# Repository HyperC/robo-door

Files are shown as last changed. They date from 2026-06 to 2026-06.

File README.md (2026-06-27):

# Automated Hidden Garage for a Roborock using ESP32 + ESPHome

A hidden garage door for the Roborock Qrevo Slim, controlled via ESPHome and Home Assistant.

Door opening and closing

## Installation Guide

### 1. Hardware

You'll need:

- **ESP32** — I used a Seeed XIAO ESP32-C6, but any ESP32 should work (C3, C6, SuperMini, etc.).
- **Metal gear servo** — I used a TD-8125MG (25 kg). It's just strong enough, although I ended up adding a counterweight to the door (explained later).
- **5V power supply** — I used a 5V / 2A adapter to power both the ESP32 and the servo.
- **(P)IR motion sensor** — Any small 5V-compatible (P)IR sensor should work.
- **3D printed parts** — Hinges, servo mount, and linkage arm (STLs attached). You could also build these from hardware store parts if your setup allows it.

### 2. Software

- Home Assistant
- ESPHome
- Roborock integration

## Door Preparation

Cut an opening large enough for the robot to pass through.

I recommend leaving roughly:

- **2–3 cm** clearance on each side
- **6–8 cm** above the robot

The extra height is needed because of the hinge design.

If possible, don't place the opening directly against a wall like I did. It makes the hinge design much more complicated.

If you're making the opening, consider cutting the top edge at roughly **45°**. When the door closes, the seam becomes much less visible and you can reduce the gap significantly.

For the door itself, use something lightweight. I used a thin piece of MDF, although lightweight plywood would probably be a better choice.

## Hinges

A normal piano hinge doesn't work very well here because:

- The hinges shouldn't be visible from the outside.
- There's no room for the door to swing inward — the robot is in the way.

Instead of rotating around a fixed pivot, the hinge creates an offset pivot point. This causes the top edge of the door to move inward first, after which the door rotates outward and upward.

Because my opening sits directly against a wall, I designed custom hinges that mount on top of the frame instead of inside it. STL files are in the [assets](./assets/) folder.

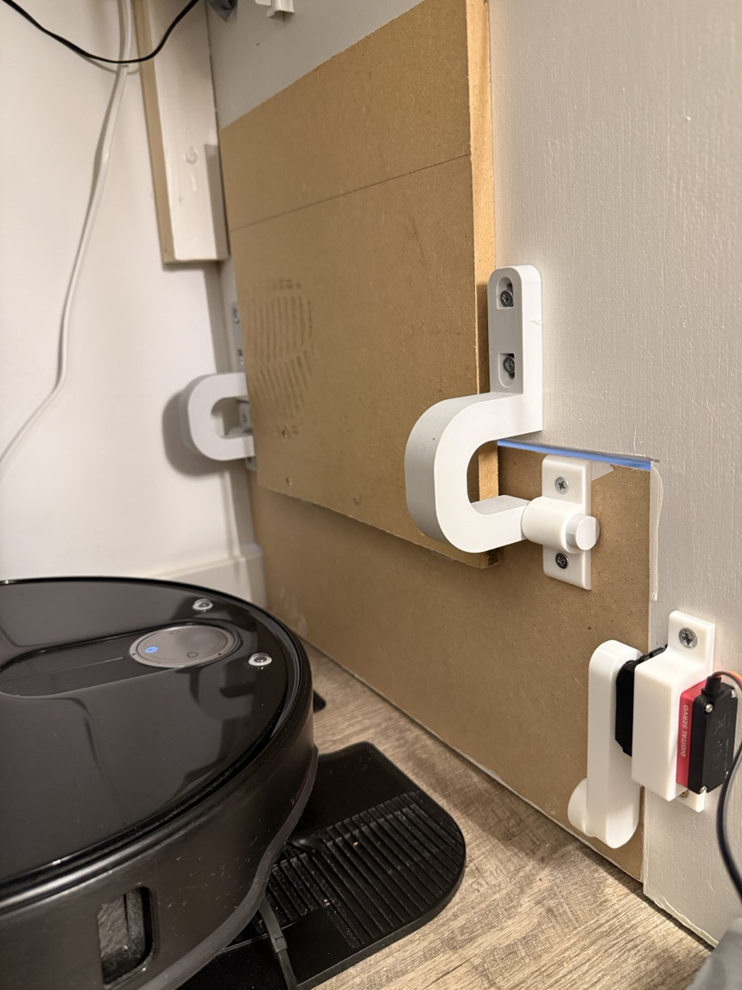
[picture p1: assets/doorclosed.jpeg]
Door closed from inside


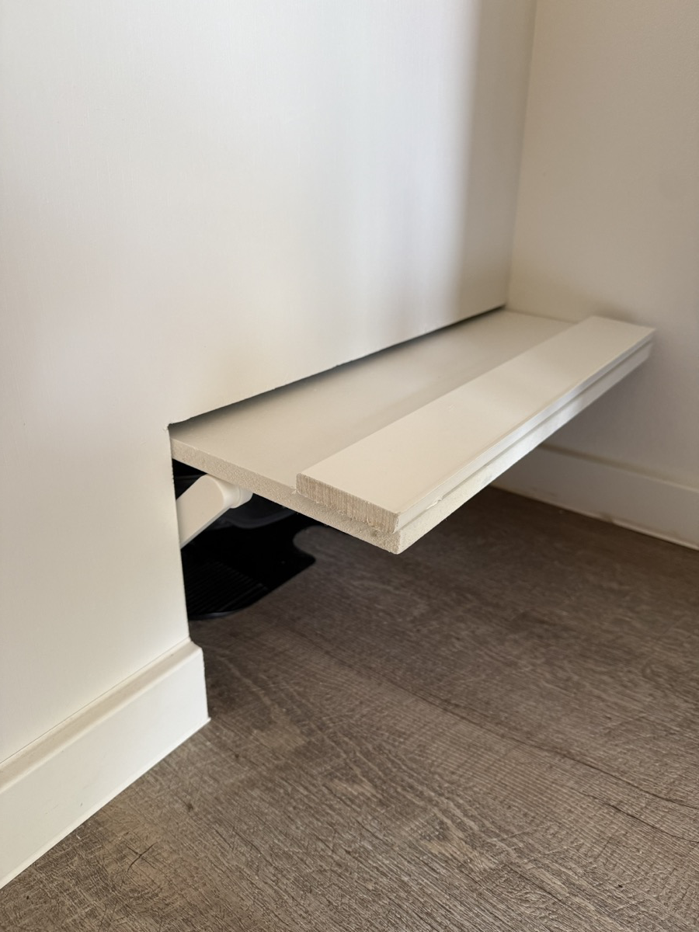
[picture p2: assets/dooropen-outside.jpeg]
Door open from outside


## Servo Installation

Mount the servo on the inside of the cabinet where it can move freely.

I designed a printable servo bracket that screws to the cabinet and keeps everything aligned. The linkage arm snaps onto the servo horn and connects to the door.

The little wheel at the end of the arm rolls against the door, which greatly reduces friction and makes opening much smoother. Glue the small retaining cap onto the wheel so it can't slide off.

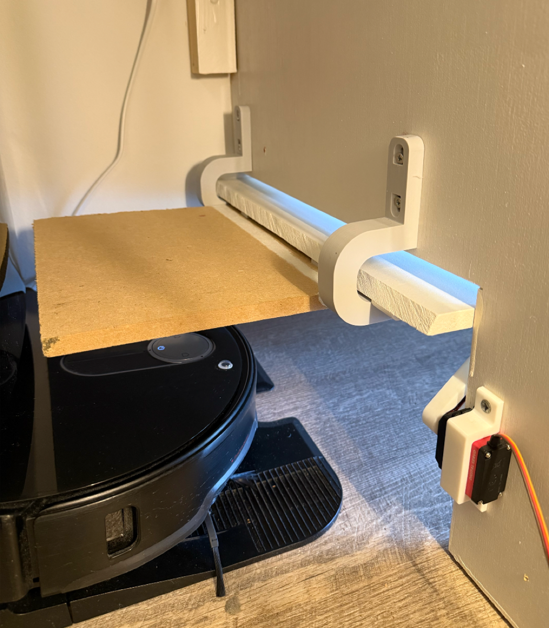
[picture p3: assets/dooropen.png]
Servo, linkage arm, and door open


## ESPHome

Create a new ESPHome device in Home Assistant and upload the following configuration:

```yaml
esphome:
  name: esphome-web-332f40
  friendly_name: Robo Door
  min_version: 2025.0.0
  name_add_mac_suffix: false

esp32:
  board: esp32-c6-devkitc-1
  variant: esp32c6
  framework:
    type: esp-idf

logger:
api:
ota:
  - platform: esphome

wifi:
  ssid: !secret wifi_ssid
  password: !secret wifi_password

# --- Servo ---
servo:
  - id: door_servo
    output: pwm_output
    auto_detach_time: 3s        # PWM stops 3s after movement
    transition_length: 1200ms
    min_level: 3%
    max_level: 12%

output:
  - platform: ledc
    id: pwm_output
    pin: GPIO23
    frequency: 50 Hz

# --- Buttons in HA ---
button:
  - platform: template
    name: "Door open"
    on_press:
      - servo.write:
          id: door_servo
          level: -55%

  - platform: template
    name: "Door close"
    on_press:
      - servo.write:
          id: door_servo
          level: 63%

# --- Manual calibration ---
number:
  - platform: template
    name: "Door manual"
    min_value: -100
    max_value: 100
    step: 5
    optimistic: true
    set_action:
      - servo.write:
          id: door_servo
          level: !lambda 'return x / 100.0;'

binary_sensor:
  - platform: gpio
    name: "Robot motion"
    id: robot_motion
    pin:
      number: GPIO2          
      mode:
        input: true
    device_class: motion
    filters:
      - delayed_off: 2s
    on_press:
      - servo.write:
          id: door_servo
          level: -55%
```

The configuration creates:

- Open button
- Close button
- Manual position slider (useful for calibration)
- Motion sensor
- Servo control

The PIR sensor immediately opens the door when it detects the robot moving. This is necessary because the Roborock API can take up to 30 seconds to report that cleaning has started, which would otherwise cause the robot to drive into the closed door.

## Wiring

The wiring is very straightforward.

The 5V adapter powers both the ESP32 and the servo. The servo and PIR sensor share the same 5V and GND connections, while each uses its own GPIO pin for the signal.

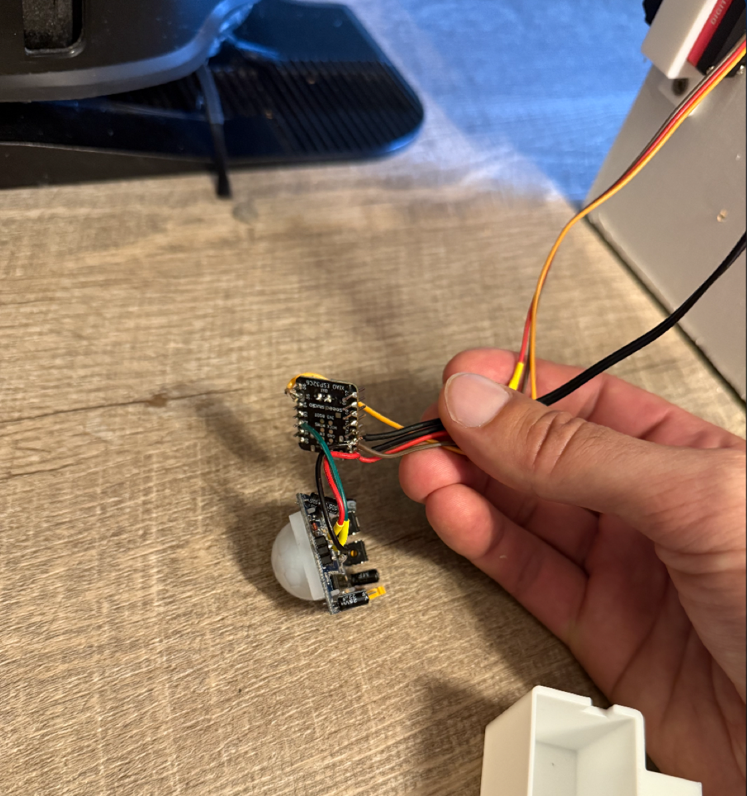
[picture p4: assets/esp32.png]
ESP32 and PIR sensor wiring


It's definitely functional, although I'll probably design a proper enclosure for the electronics later.

## Counterweight

One problem I ran into was that the servo wasn't strong enough to reliably hold the door open once power was removed. I could have kept the servo energized continuously, but I'd rather avoid that.

Instead, I added a simple counterweight to the inside of the door (just an extra piece of MDF). Now the door is almost perfectly balanced, with the outside still being slightly heavier so it naturally closes once the servo lowers the arm.

This also means ESPHome can safely detach the servo after opening (`auto_detach_time`), so the servo isn't constantly drawing power.

## Home Assistant Automations

Finally, I added a few Home Assistant automations using the Roborock integration.

The motion sensor opens the door immediately. The Roborock state is then used to determine when it's safe to close it again. For example, I close the door after the robot has finished drying its mop:

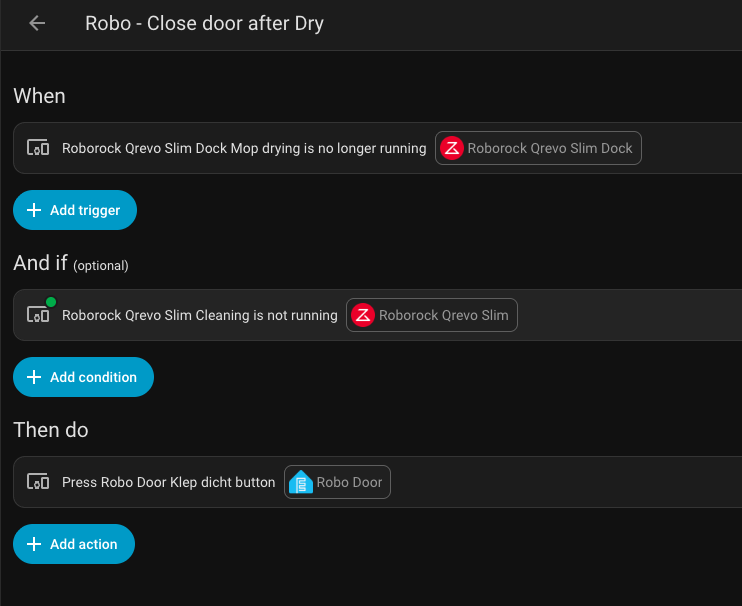
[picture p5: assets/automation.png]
Close door after mop drying automation


## That's it!

If anything is unclear, or if you'd like the Shapr3D files, or more details about the ESPHome configuration, just let me know. I'm happy to share everything.

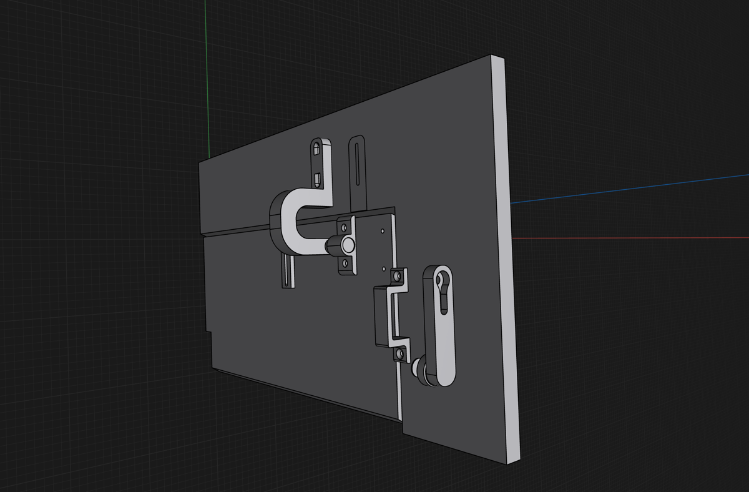
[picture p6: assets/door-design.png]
Hinge mechanism design


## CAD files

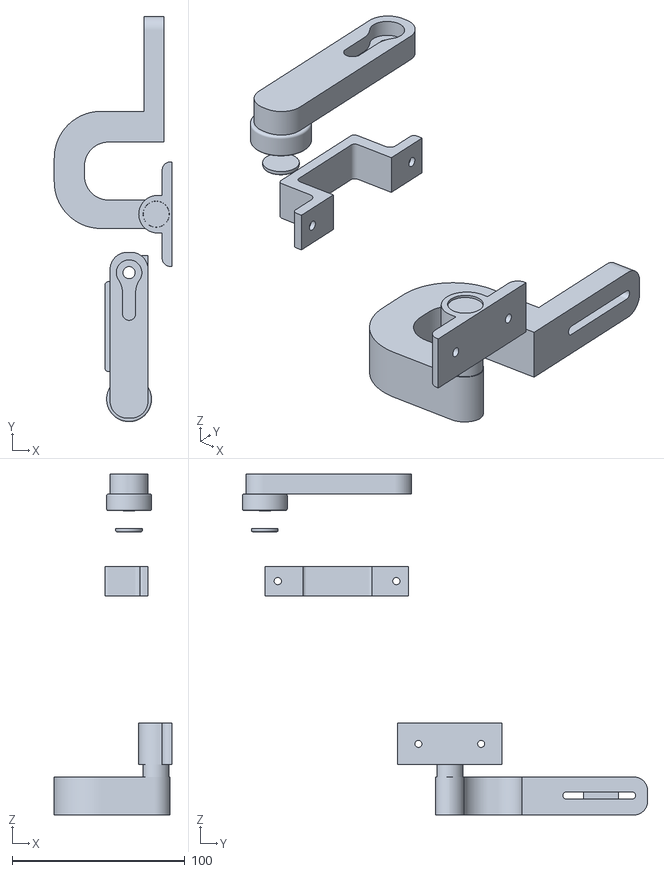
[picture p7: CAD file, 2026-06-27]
assets/door.stl
68.0 x 234.6 x 197.3
